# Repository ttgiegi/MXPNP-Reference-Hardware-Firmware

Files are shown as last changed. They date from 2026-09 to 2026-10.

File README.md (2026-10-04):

# MXPNP Legacy Hardware & Firmware

<p>
  <picture>
    <source media="(prefers-color-scheme: dark)" srcset="branding/c02/mxpnp-white.svg">
    MXPNP — by MX TECH / 萌新科技
  </picture>
</p>

[Official C02 SVG assets](branding/c02/)

This repository is a public reference archive for historical and superseded MXPNP hardware designs and legacy firmware.

## About

The contents represent earlier generations of MXPNP development. They may have been replaced by newer hardware and software architectures and are not expected to receive ongoing maintenance.

## Repository Scope

Released hardware designs may include manufacturing and reference material such as Gerber files, drill files, bills of materials (BOMs), pick-and-place files, schematic PDFs, and related documentation. Original CAD source files may not always be provided.

Legacy firmware may include modified versions or configurations of upstream projects, such as Marlin. Each component should retain its appropriate upstream attribution and license information.

## Repository Structure

```text
hardware/     Legacy hardware designs and manufacturing/reference files
firmware/     Legacy firmware sources and configurations
docs/         Design-specific notes and reference documentation
```

Directories will be added as legacy designs are archived.

## Status Labels

- `LEGACY`: Historical design retained for reference.
- `SUPERSEDED`: Replaced by a newer design or implementation.
- `EXPERIMENTAL`: Incomplete or intended for experimentation.
- `UNTESTED`: Not recently verified.

## Legacy Hardware

Hardware releases are provided for study, manufacturing of an older design, porting work, and experimentation. Availability and completeness vary by design.

### PCB Design Notes

Design-specific scope, upstream references, release contents, and known limitations are documented on these Wiki pages:

- [Smoothieware Control Board](https://github.com/ttgiegi/MXPNP-Reference-Hardware-Firmware/wiki/Smoothieware-Control-Board)
- [Six-Axis Pick-and-Place Mainboard](https://github.com/ttgiegi/MXPNP-Reference-Hardware-Firmware/wiki/Six%E2%80%90Axis-Pick%E2%80%90and%E2%80%90Place-Mainboard)
- [Nine-Axis Pick-and-Place Mainboard](https://github.com/ttgiegi/MXPNP-Reference-Hardware-Firmware/wiki/Nine%E2%80%90Axis-Pick%E2%80%90and%E2%80%90Place-Mainboard)
- [MXPNP Marlin v1.0 Motion Controller](https://github.com/ttgiegi/MXPNP-Reference-Hardware-Firmware/wiki/MXPNP-Marlin-v1.0-Motion-Controller)

## Legacy Mechanical Designs

The archive also includes historical CoreXY mechanical-design references for DIY study and experimentation. They are marked `LEGACY`, `EXPERIMENTAL`, and `UNTESTED`; they are not validated machine designs and are not recommended for direct production use.

The large design archives are distributed through the [CoreXY Mechanical Reference Release](https://github.com/ttgiegi/MXPNP-Reference-Hardware-Firmware/releases/tag/legacy-corexy-v1.0.0). See the [CoreXY Mechanical Reference Designs Wiki page](https://github.com/ttgiegi/MXPNP-Reference-Hardware-Firmware/wiki/CoreXY-Mechanical-Reference-Designs) for download guidance, checksums, and known limitations.

## Legacy Firmware

Firmware releases are retained as historical implementations and configurations. Compatibility with current MXPNP hardware or software is not guaranteed.

## Licensing and Attribution

License and attribution information, including applicable upstream notices, is provided with the relevant component where available.

## Current MXPNP Project

This repository is distinct from the current MXPNP project and its documentation. Refer to the current MXPNP project repository and documentation location when available: `CURRENT_MXPNP_PROJECT_URL`.

## Disclaimer

Legacy designs are provided for reference and experimentation. They are not guaranteed to be compatible with current MXPNP hardware or software, production-ready, safe, or actively supported unless a particular design explicitly states otherwise.

## Contact
For questions about uncertain or archive-specific information, contact `1025971921@qq.com`.

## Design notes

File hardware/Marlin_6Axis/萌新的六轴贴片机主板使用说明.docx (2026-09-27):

# 萌新的六轴贴片机主板使用说明

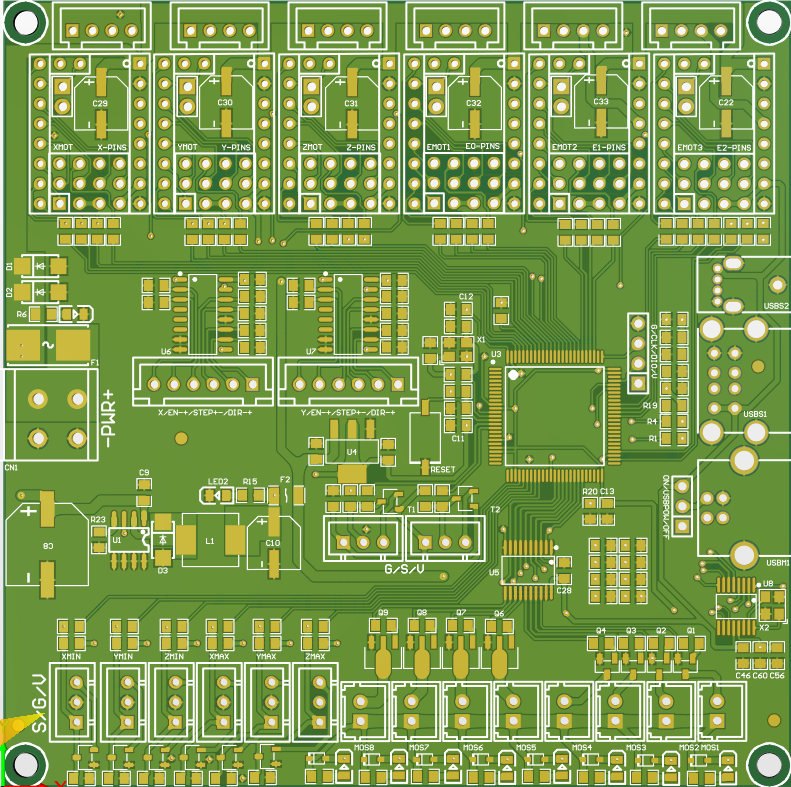
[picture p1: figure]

## 一：萌新主板简介

萌新六轴主板是本萌新针对openpnp项目开发的专用于双贴头的高性价比运动控制板，特别适用于DIY的小型贴片机使用。

## 二：萌新主板特点

1）采用32位主频72MHz的ARM级Cortex-M3系列stm32103ve主控芯片，性能大幅提升；

2）搭载高度模块化开源固件Marlin2.0，方便用户DIY及二次开发；

3）板载TMC驱动的SPI工作模式和UART工作模式，且板载DIAG功能引脚，方便客户使用，省去复杂的接线过程，只需通过简单的拔插跳线帽即可使用；

4）采用高性能MOSFET管，驱动8路外设满足小型机使用需求；

5）采用可拔插的保险丝，更换过程更加简易；

6）使用电源选择设计，让USB电源与开关电源分开，有效避免由于短路导致电脑USB口被烧毁的情况发生；

7）预留闭环驱动接口，省去外插转接模块的烦恼；

8）双Y轴接口，省去外接驱动拓展模块的烦恼；

9）压力传感器接口使用钳位二极管进行保护，增强接口的抵抗能力；

## 三：萌新主板参数

外观尺寸：100*100mm

安装尺寸：94.5*94.5mm

微处理器：ARM Cortex-M3 CPU

输入电压：DC24V

逻辑电压：DC 3.3V

电机驱动器：支持TMC5161、TMC5160、TMC2209、TMC2225、TMC2208、TMC2130、ST820、LV8729、DRV8825、A4988等，可单独外接电机驱动

驱动工作模式支持：SPI、UART、STEP/DIR

电机驱动接口：X、Y、Y2、Z、A、 B，六路（X和Y有一个闭环驱动接口），最高可达256细分

真空传感器接口：T0、T1。2路

PC通信接口：方形USB，方便插拔，通信波特率115200

支持文件格式：G-code

支持机器结构：XYZ、delta、kossel、Ultimaker、corexy

## 四：萌新主板通电

此处为24v供电输入，注意不可接反！！

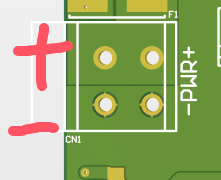
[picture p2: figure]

此处跳线帽用于选择是用USB给主板供电还是24V给主板供电 跳线帽连接靠上两个引脚为usb供电靠下为24v，正常使用建议连接靠下两个

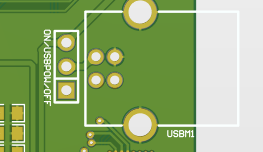
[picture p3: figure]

## 五、主板与电脑通信

主板通过【USB】接口与电脑通信，需要电脑先安装驱动程序后，再将主板插入电脑，方可识别端口进行数据传输。WINDOWS一般会自动安装，如果不识别考虑安装驱动程序。

## 六、主板接口说明

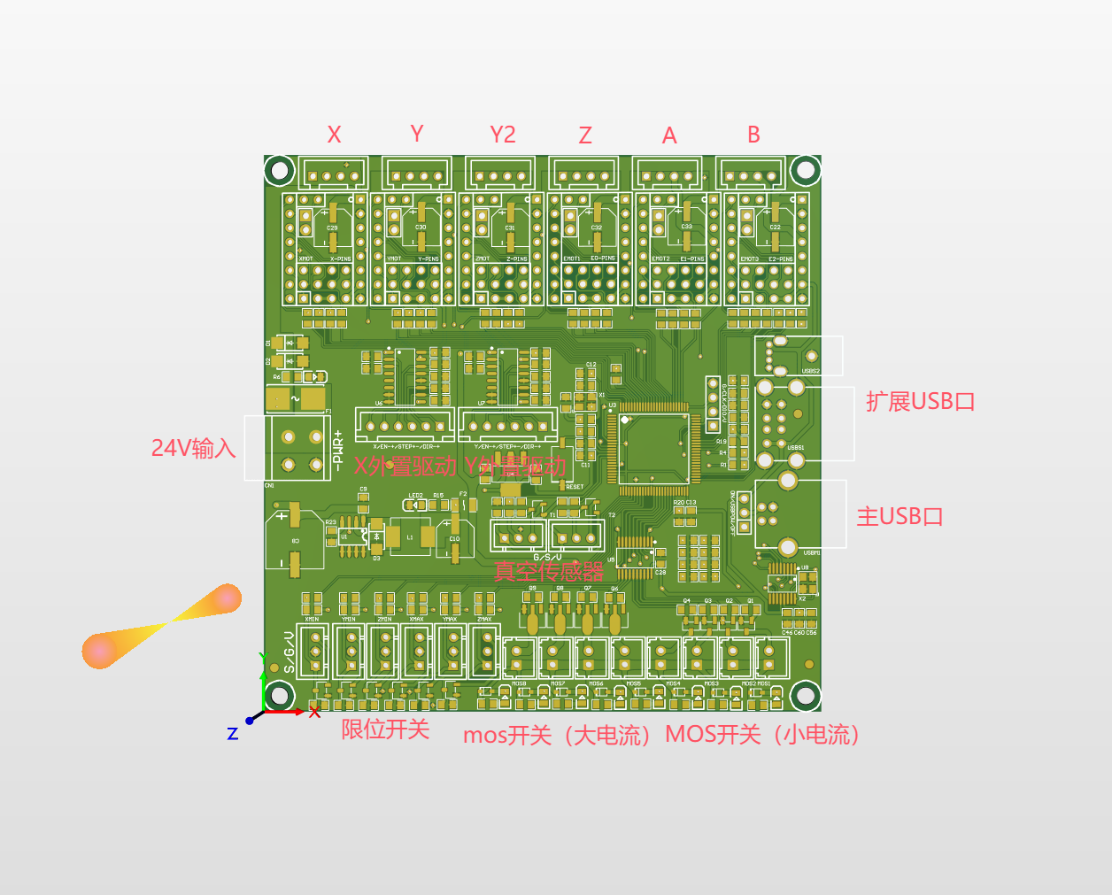
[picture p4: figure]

电机接口如上图标注，默认引脚定义如上图如果需要重新修改可在固件中进行重映射。电机接口四个引脚从左往右相邻两个引脚为电机的一相。两相顺序更换之后只会影响电机旋转方向。24V输入接口上正下负不可接反！！！板子中间两个6p接口分别为外接XY轴驱动的差分信号输出口，具体线序参照板子上的丝印。限位开关接口板子上标出了定义，MIN为最小限位，MAX为最大限位。左侧标注的s/g/v分别表示横向那一排引脚的定义，s代表限位信号g为地，V为5v供电。Mos开关左侧四个接口为大封装mos可以带一些电流比较大的负载例如气泵，右侧4个为小封装可以带一些小电流负载例如补光灯，小电磁阀等。正负极引脚定义如图

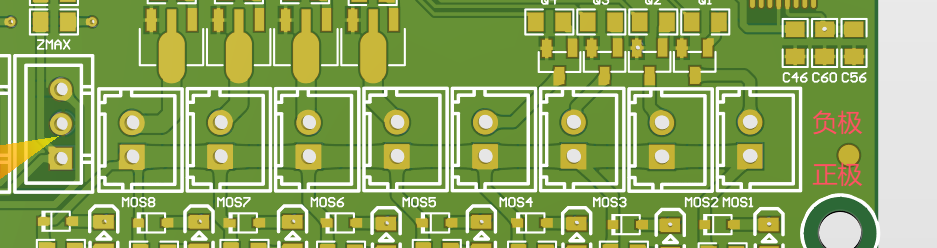
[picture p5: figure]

以上MOS开关由自定义G代码控制格式以及使用方法如图

主USB口连接电脑，其余扩展口可用于连接摄像头以及飞达控制器等。

驱动工作模式选择方法：

1 普通的STEP/DIR模式：（如：A4988、DRV8825、LV8729、ST820等）根据驱动细分表来选择短路帽短接MS1-MS2。

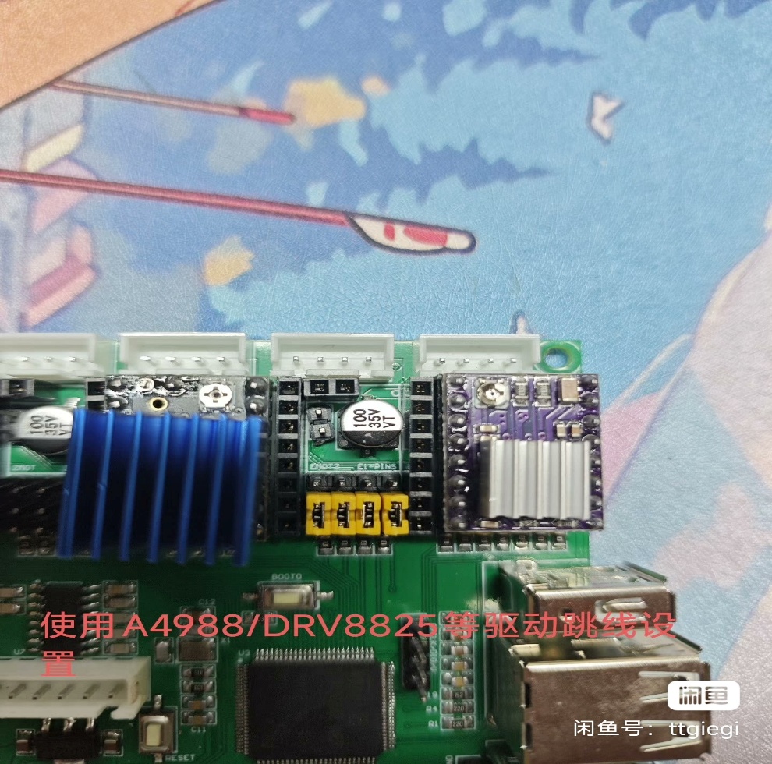
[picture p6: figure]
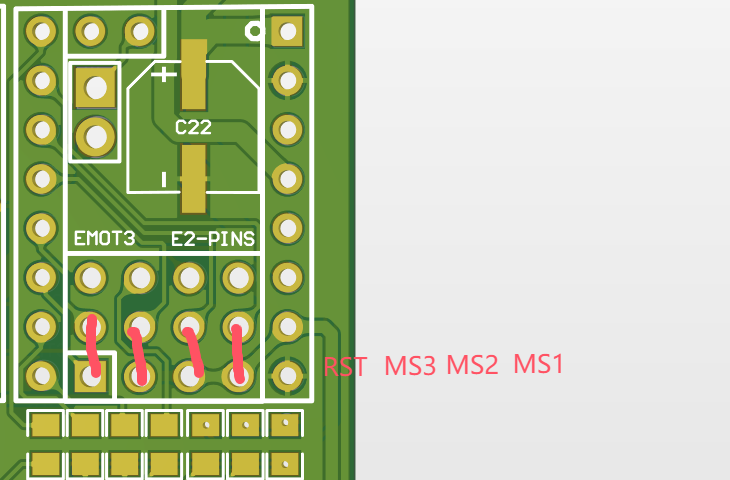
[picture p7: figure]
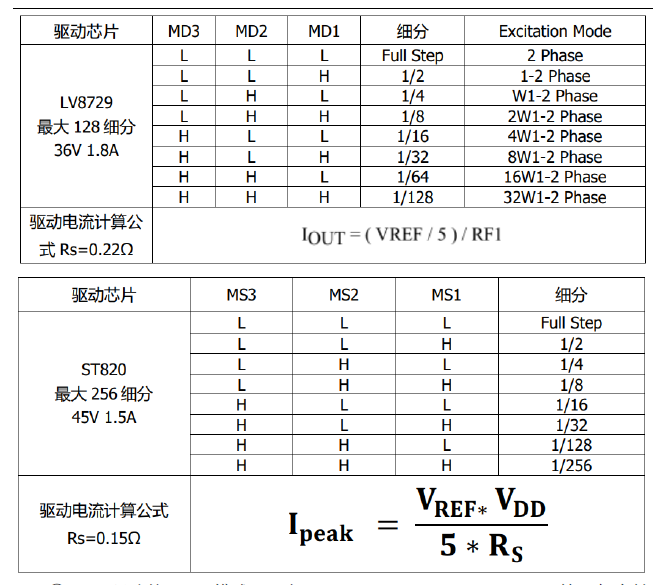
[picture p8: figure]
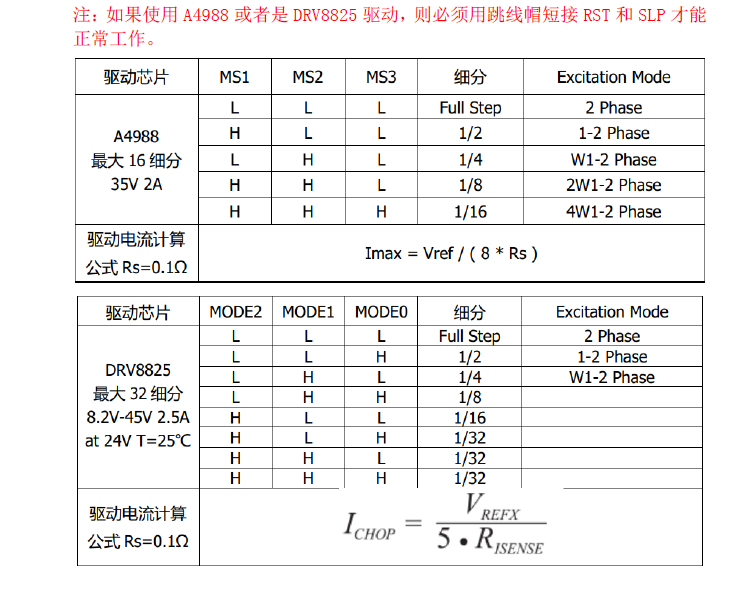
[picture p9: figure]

② TMC驱动的UART模式：（如：TMC2208、TMC2209、TMC2225等）每个轴使用一个短路帽短接图中红框位置即可，细分和驱动电流通过固件进行设置。

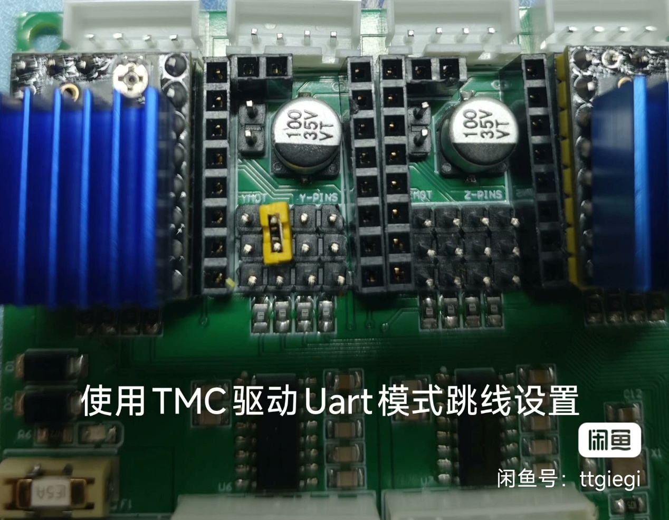
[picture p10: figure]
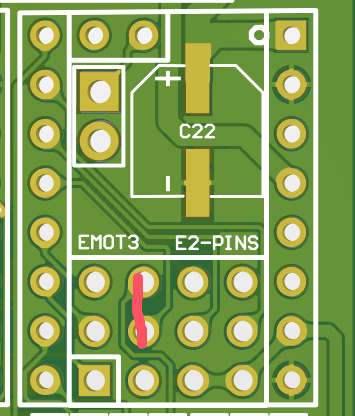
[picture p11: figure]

③ TMC驱动的SPI模式：（如：TMC2130、TMC5160、TMC5161等）每个轴使用四个短路帽短接图中红框位置即可，细分和驱动电流通过固件进行设置。

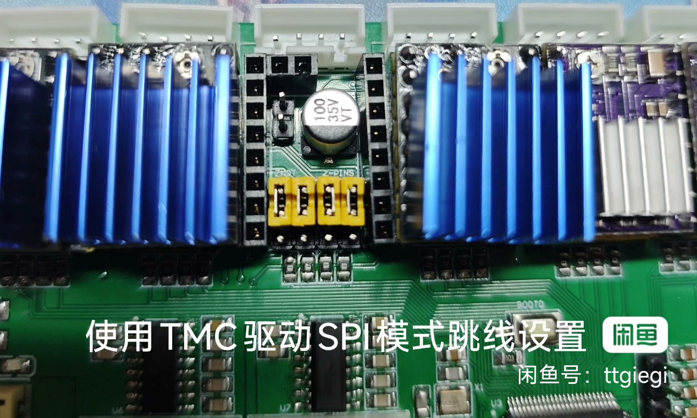
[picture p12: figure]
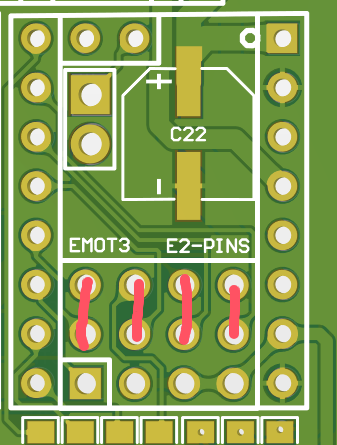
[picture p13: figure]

如果需要使用无限位归零那么需要连接跳线帽如图所示

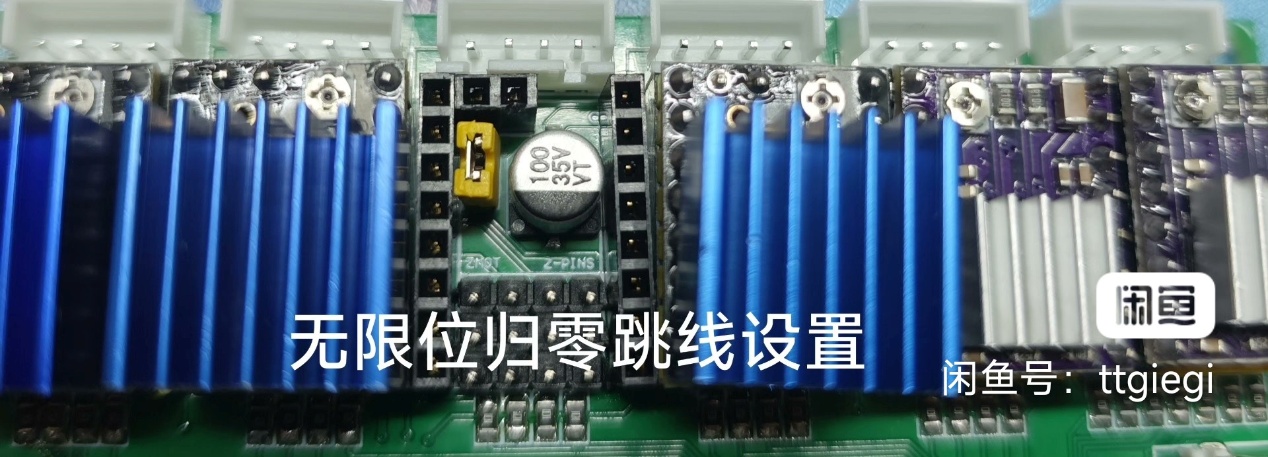
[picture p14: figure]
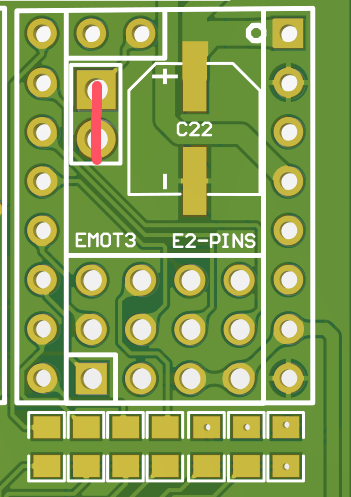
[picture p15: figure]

6个驱动的无限位归零信号分别连接到X-XMIN/Y-YMIN/Y2-ZMIN/Z-XMAX/A-YMAX/B-ZMAX

以上定义均可自己在固件中修改。

## 七、固件编译与修改

主板采用Marlin2作为固件，具有很高的使用自由度，几乎兼容各种结构的机器。

编译环境搭建可以参照以下链接

https://blog.csdn.net/jslovesky/article/details/110133431

第一步安装vscode 不再赘述

第二步进入vscode后点击

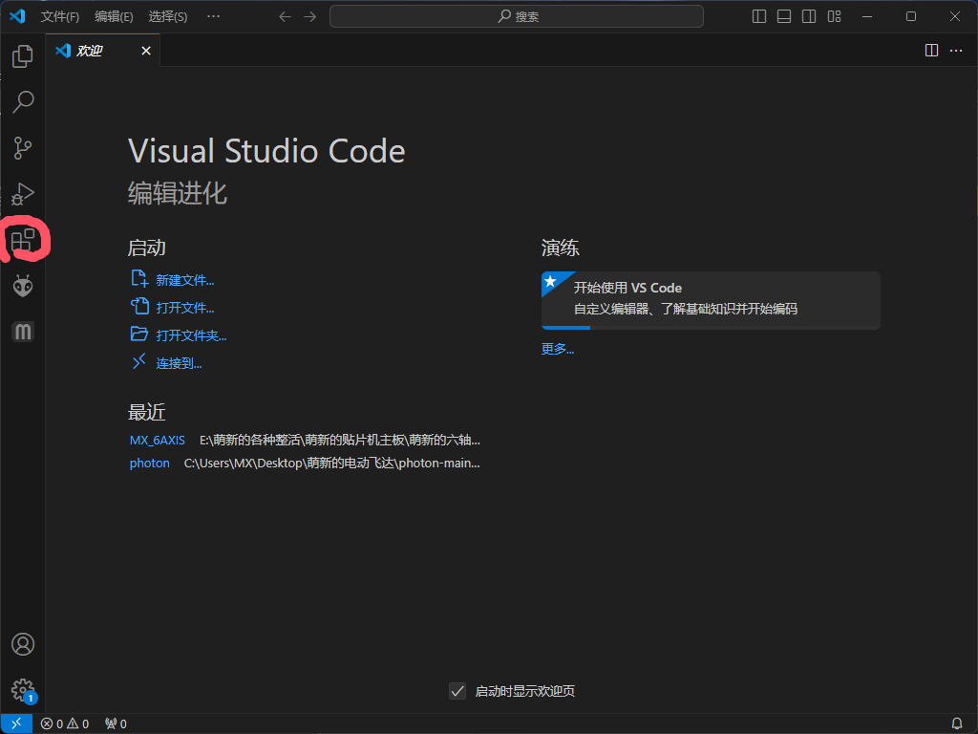
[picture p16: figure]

在其中搜索platformio并且安装整个过程基本上自动完成

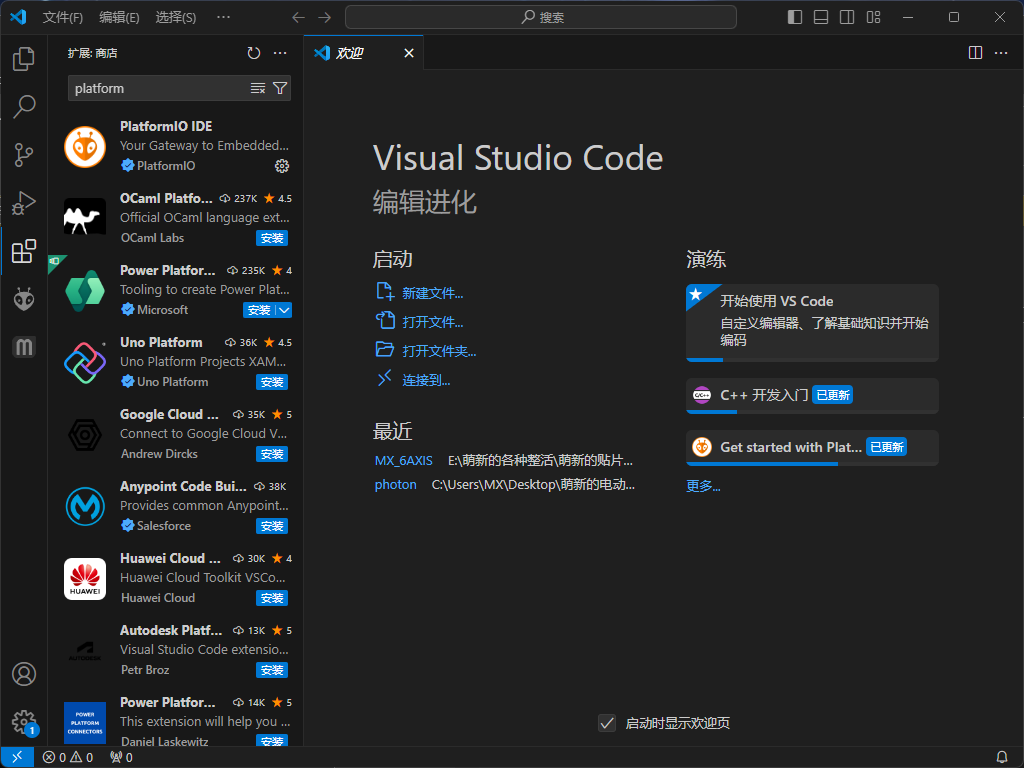
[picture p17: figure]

安装完成后点击vscode的 文件-打开文件夹 选中萌新提供的固件包，编译的相关参数已经配置好，只需要根据自己的需要修改configuration,h以及configuration.adv.h中的相关内容并且编译即可使用下载器上传进主板中使用

编译出的固件的路径如下.pio\build\STM32F103VE

名字叫firmware.bin

如何修改固件有很多教程这里不再赘述。

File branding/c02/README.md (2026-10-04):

# MX TECH / MXPNP — C02 brand assets

Approved identity: C02 (开放方切), adopted on 2026-10-04. MXPNP is a project of MX TECH / 萌新科技; both share the same geometric symbol.

<picture>
  <source media="(prefers-color-scheme: dark)" srcset="mxpnp-white.svg">
  MXPNP — by MX TECH / 萌新科技
</picture>

## SVG files

| Asset | Primary | Black / PCB | White / dark backgrounds |
| --- | --- | --- | --- |
| Shared icon | [icon.svg](icon.svg) | [icon-mono.svg](icon-mono.svg) | [icon-white.svg](icon-white.svg) |
| MX TECH + 萌新科技 | [mx-tech.svg](mx-tech.svg) | [mx-tech-mono.svg](mx-tech-mono.svg) | [mx-tech-white.svg](mx-tech-white.svg) |
| MXPNP + studio credit | [mxpnp.svg](mxpnp.svg) | [mxpnp-mono.svg](mxpnp-mono.svg) | [mxpnp-white.svg](mxpnp-white.svg) |
| Studio wordmark | [wordmark.svg](wordmark.svg) | [wordmark-mono.svg](wordmark-mono.svg) | [wordmark-white.svg](wordmark-white.svg) |

All SVGs have transparent backgrounds and outlined lettering. They contain native vector paths without embedded bitmaps, external fonts, gradients or filters. Primary color: `#173B4B`; monochrome: `#000000`; reversed: `#FFFFFF`.

The README and Wiki use the primary version on light backgrounds and the reversed version on dark backgrounds. Use monochrome exports for PCB silkscreen or engraving, and check the letter openings at the intended manufacturing size.

These are approved exports of the C02 master maintained in the MXPNP application repository. They provide project identity; hardware status, compatibility and upstream attribution remain documented with each archived design.

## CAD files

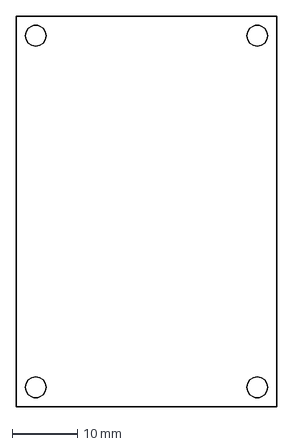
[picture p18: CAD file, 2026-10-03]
hardware/MXPNP_Marlin_v1.0/MXPNP_V1.0_ToolHead/mxpnp一代集线板.DXF
40.0 x 60.0 mm

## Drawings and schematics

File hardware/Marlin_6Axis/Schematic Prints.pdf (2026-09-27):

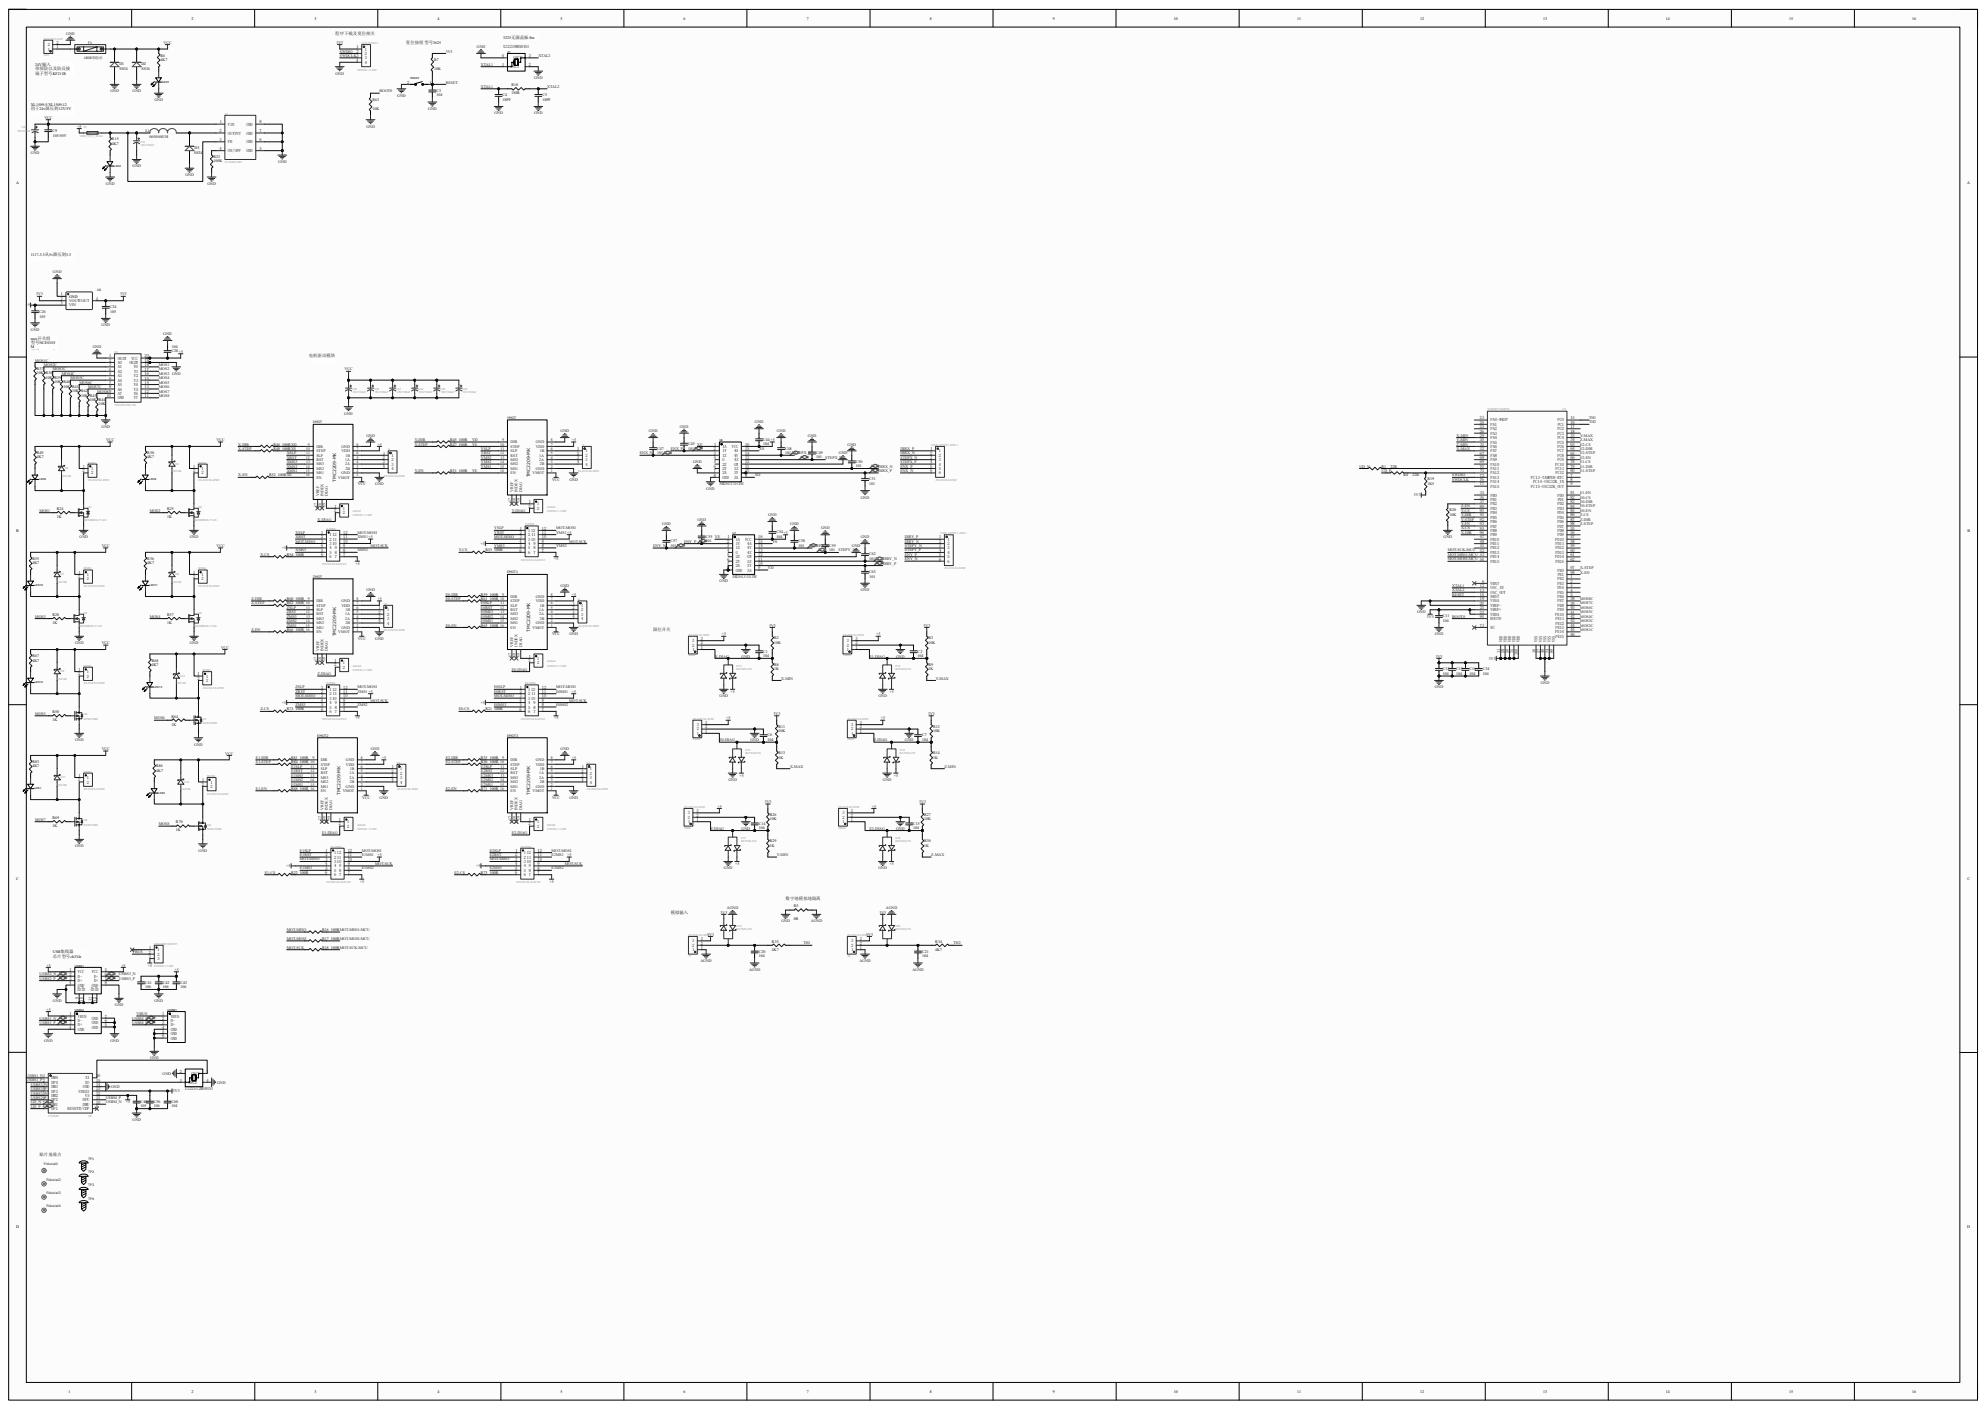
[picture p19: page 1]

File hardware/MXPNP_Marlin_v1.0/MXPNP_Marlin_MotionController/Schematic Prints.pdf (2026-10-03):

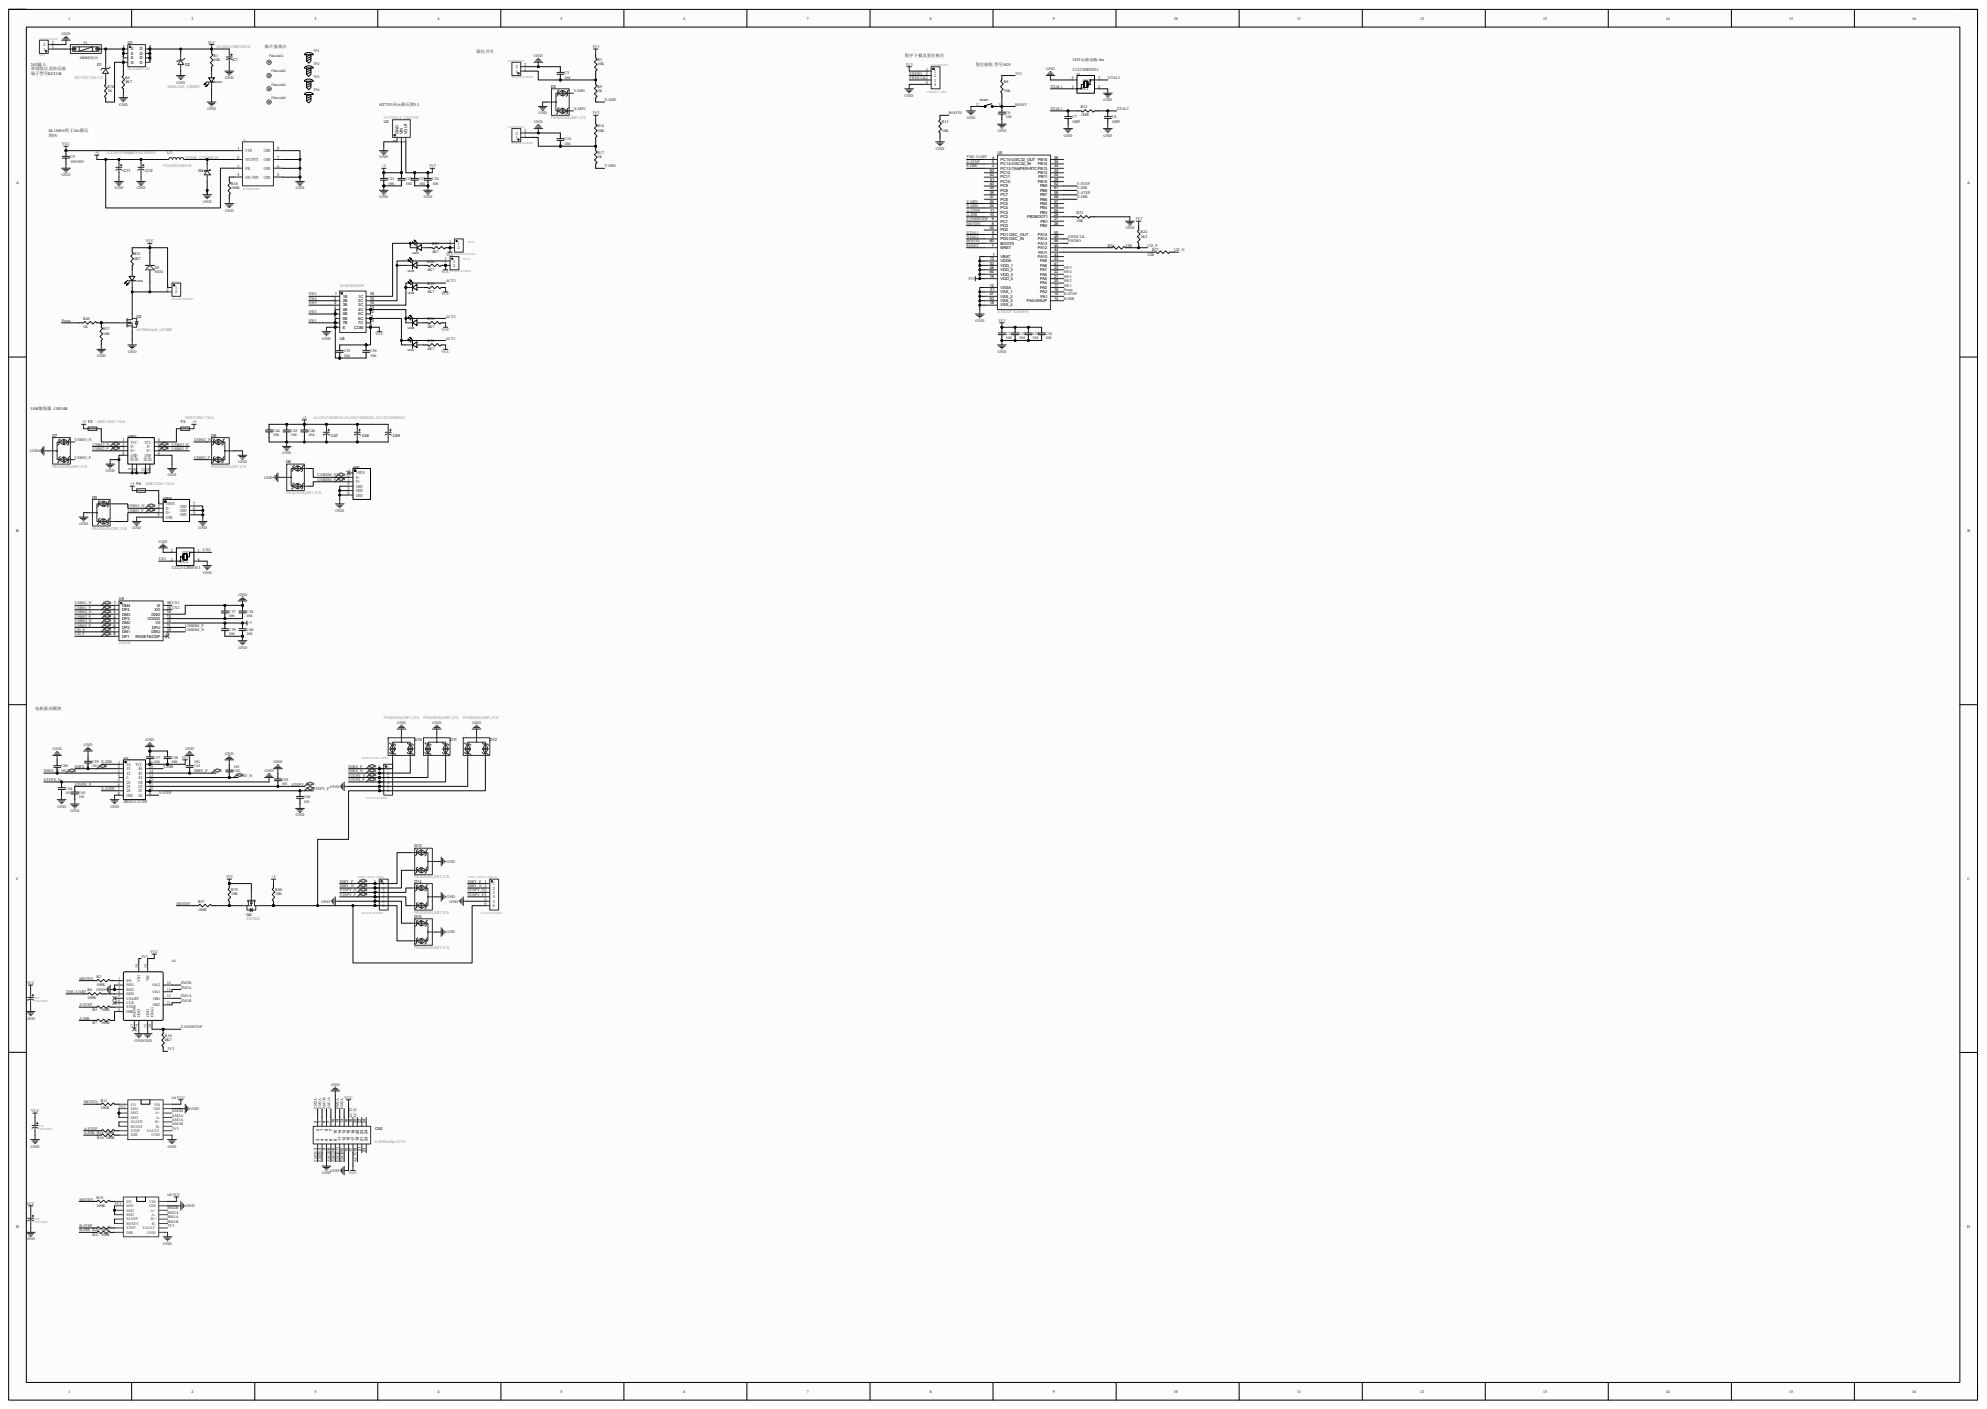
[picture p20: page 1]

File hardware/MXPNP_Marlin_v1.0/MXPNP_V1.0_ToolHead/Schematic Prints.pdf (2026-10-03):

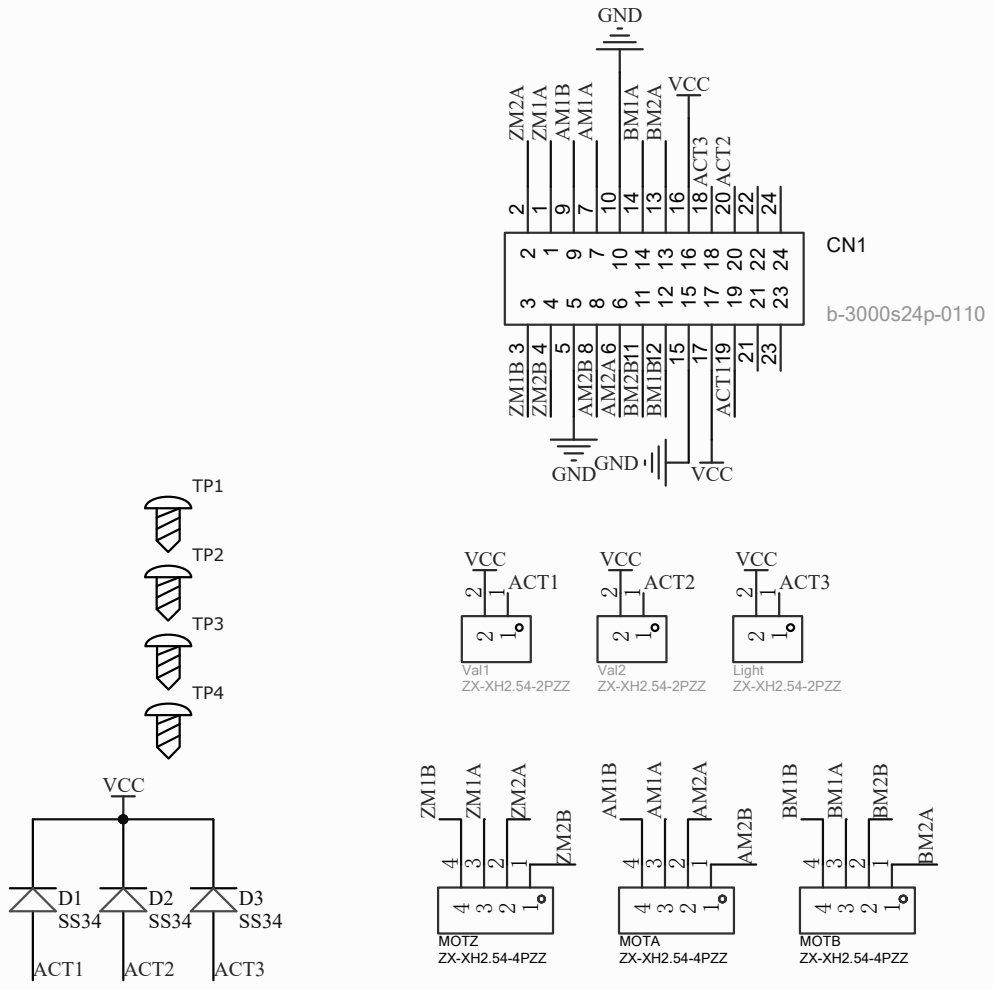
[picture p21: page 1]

Size A2 | Number | Revision

Date: 10/03/2026 | Sheet of
File: C:\Users\..\MXPNP一代集线板.SchDoc Drawn By:

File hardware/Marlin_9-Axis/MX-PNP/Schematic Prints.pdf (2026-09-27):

6 6 | 5 5 | 4 4 | 3 3 | 2 2 | 1 1

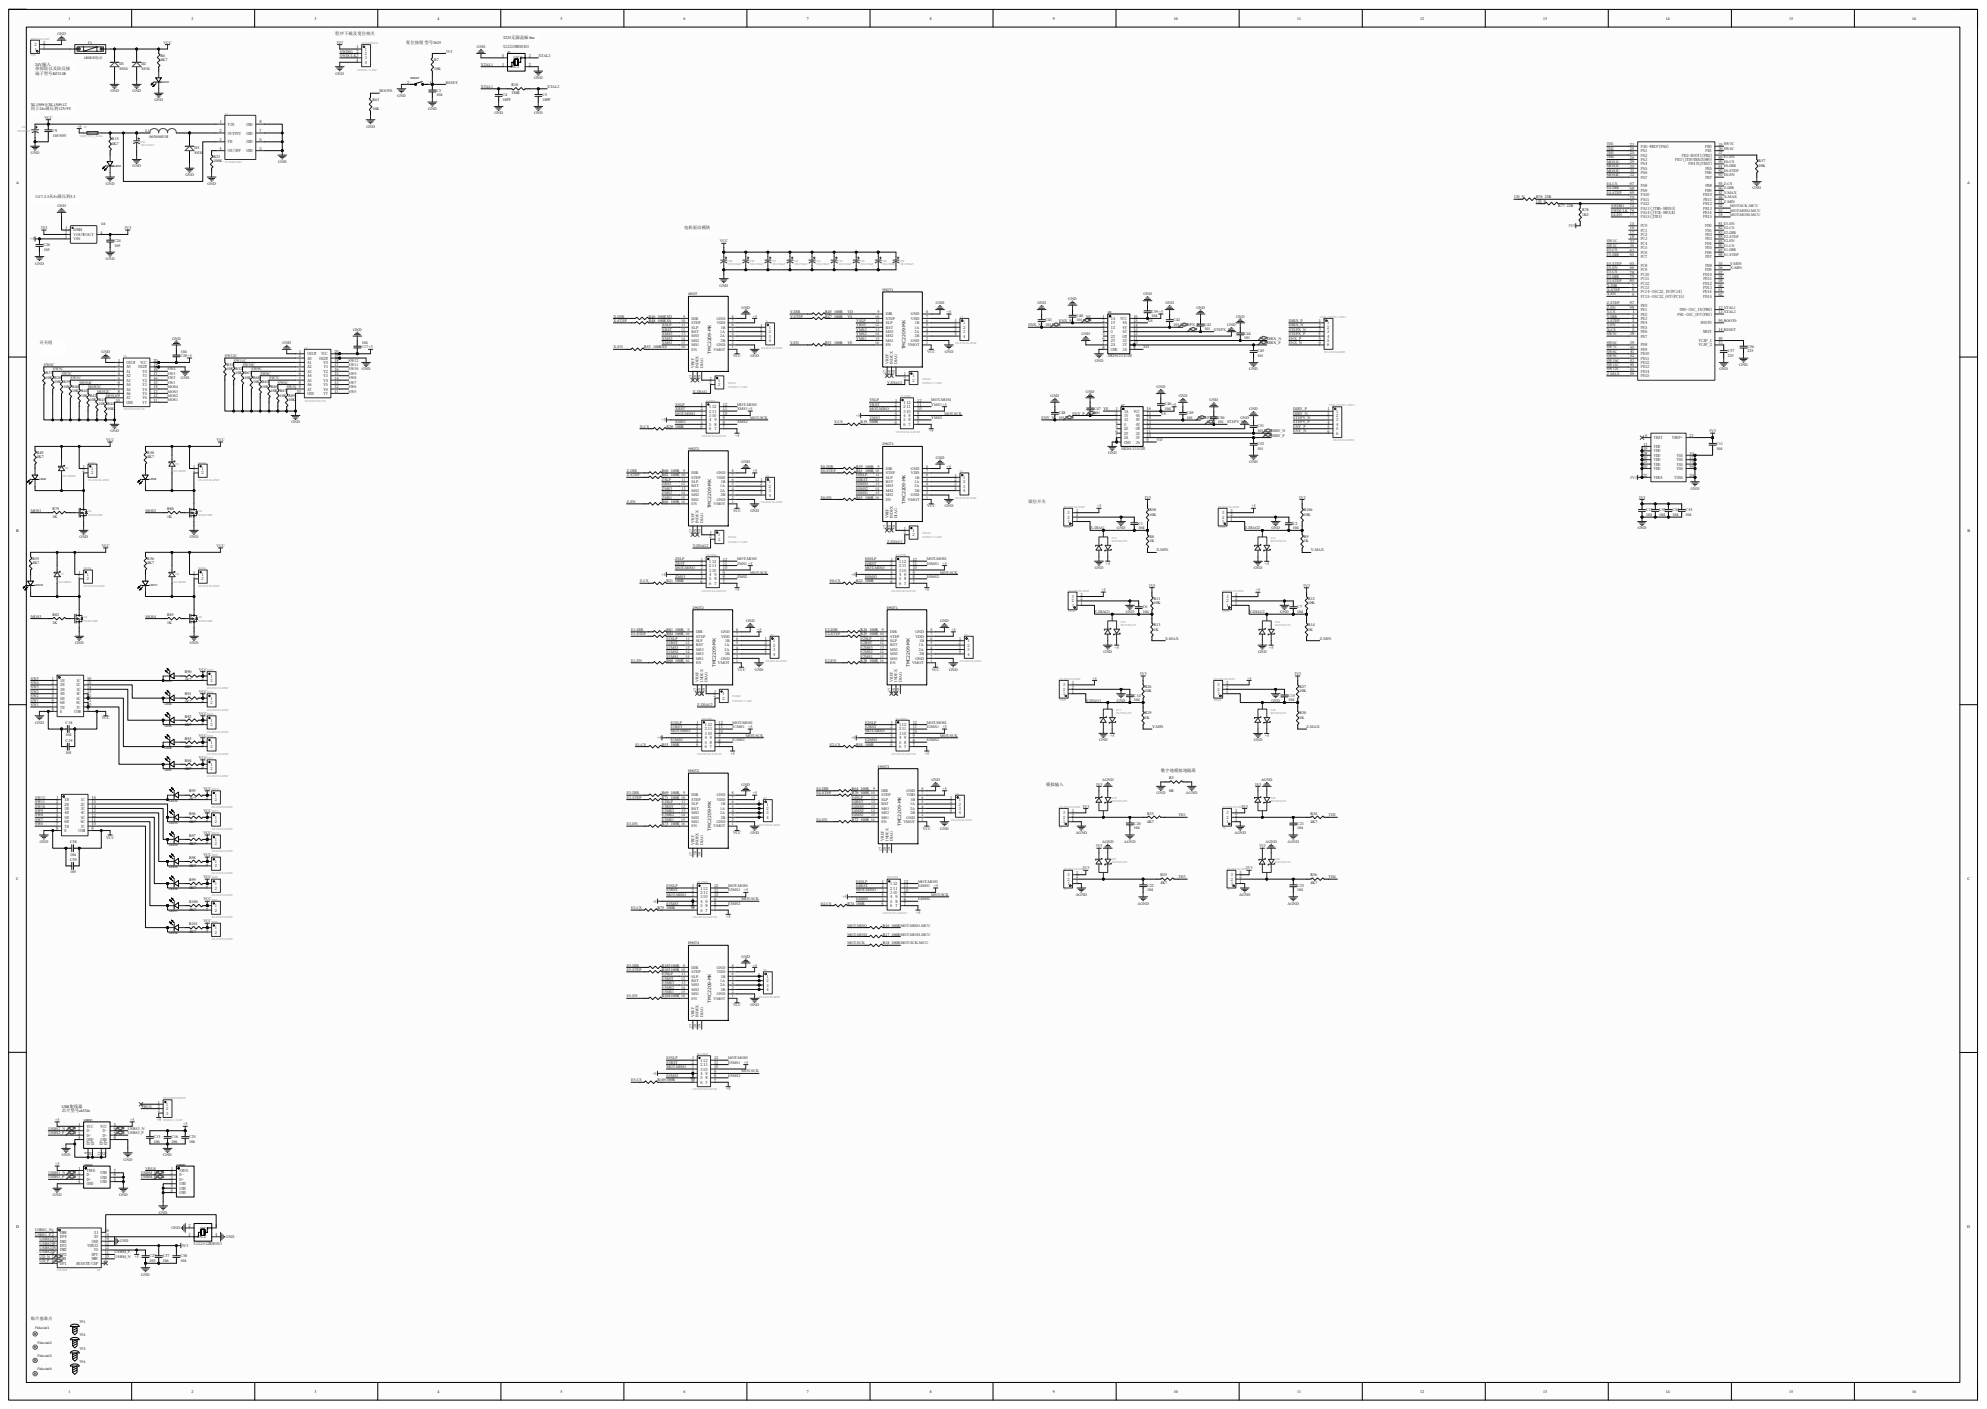
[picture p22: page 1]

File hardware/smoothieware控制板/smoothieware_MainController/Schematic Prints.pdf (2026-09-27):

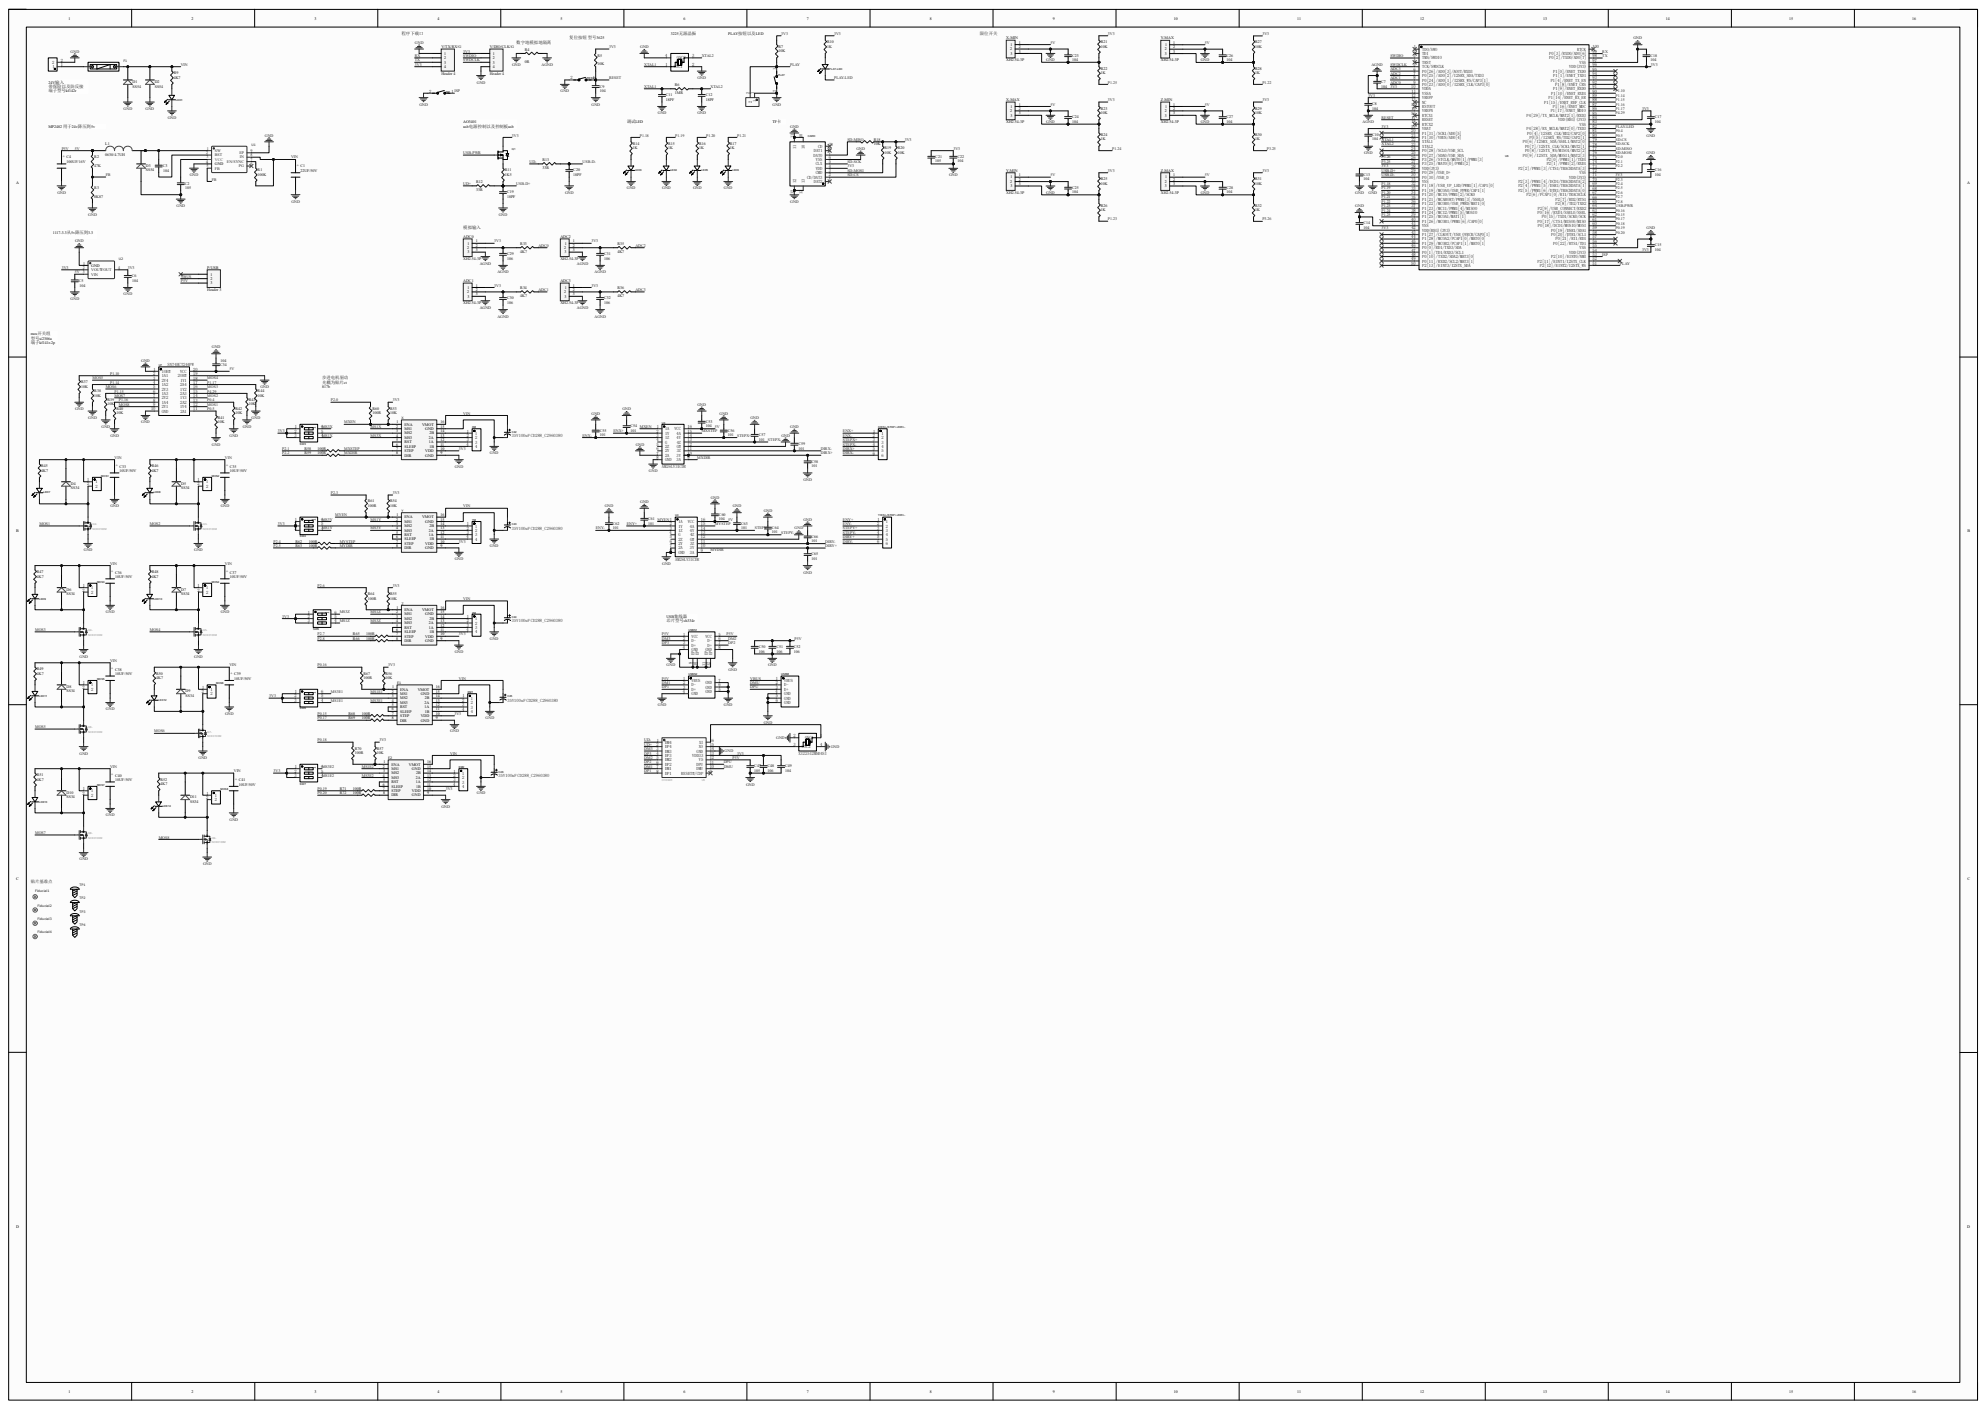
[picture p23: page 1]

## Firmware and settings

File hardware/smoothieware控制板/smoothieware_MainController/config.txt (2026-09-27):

# Smoothieboard configuration file, see http://smoothieware.org/configuring-smoothie
# NOTE Lines must not exceed 132 characters, and '#' characters mean what follows is ignored
## Robot module configurations : general handling of movement G-codes and slicing into moves

# Basic motion configuration
default_feed_rate                            4000             # Default speed (mm/minute) for G1/G2/G3 moves
default_seek_rate                            4000             # Default speed (mm/minute) for G0 moves
mm_per_arc_segment                           0.0              # Fixed length for line segments that divide arcs, 0 to disable
#mm_per_line_segment                         5                # Cut lines into segments this size
mm_max_arc_error                             0.01             # The maximum error for line segments that divide arcs 0 to disable
                                                              # note it is invalid for both the above be 0
                                                              # if both are used, will use largest segment length based on radius

# Arm solution configuration : Cartesian robot. Translates mm positions into stepper positions
# See http://smoothieware.org/stepper-motors
alpha_steps_per_mm                           100               # Steps per mm for alpha ( X ) stepper
beta_steps_per_mm                            100               # Steps per mm for beta ( Y ) stepper
gamma_steps_per_mm                           200             # Steps per mm for gamma ( Z ) stepper

# Planner module configuration : Look-ahead and acceleration configuration
# See http://smoothieware.org/motion-control
acceleration                                 3000             # Acceleration in mm/second/second.
#z_acceleration                              500              # Acceleration for Z only moves in mm/s^2, 0 uses acceleration which is the default. DO NOT SET ON A DELTA
junction_deviation                           0.05             # See http://smoothieware.org/motion-control#junction-deviation
#z_junction_deviation                        0.0              # For Z only moves, -1 uses junction_deviation, zero disables junction_deviation on z moves DO NOT SET ON A DELTA

# Cartesian axis speed limits
x_axis_max_speed                             120000            # Maximum speed in mm/min
y_axis_max_speed                             100000            # Maximum speed in mm/min
z_axis_max_speed                             30000             # Maximum speed in mm/min

# Stepper module configuration
# Pins are defined as  ports, and pin numbers, appending "!" to the number will invert a pin
# See http://smoothieware.org/pin-configuration and http://smoothieware.org/pinout
alpha_step_pin                             2.1              # Pin for alpha stepper step signal
alpha_dir_pin                                2.2!              # Pin for alpha stepper direction, add '!' to reverse direction
alpha_en_pin                                2.0              # Pin for alpha enable pin
alpha_max_rate                               120000.0          # Maximum rate in mm/min

beta_step_pin                               2.4              # Pin for beta stepper step signal
beta_dir_pin                                 2.5            # Pin for beta stepper direction, add '!' to reverse direction
beta_en_pin                                2.3             # Pin for beta enable
beta_max_rate                                100000.0          # Maxmimum rate in mm/min

gamma_step_pin                               2.7              # Pin for gamma stepper step signal
gamma_dir_pin                               2.8!             # Pin for gamma stepper direction, add '!' to reverse direction
gamma_en_pin                                 2.6             # Pin for gamma enable
gamma_max_rate                              30000.0            # Maximum rate in mm/min


# A axis

 delta_steps_per_mm                           17.7778             # may be steps per degree for example
 delta_step_pin                               0.15              # Pin for delta stepper step signal
 delta_dir_pin                               0.17!             # Pin for delta stepper direction
 delta_en_pin                                0.16              # Pin for delta enable
delta_max_rate                               60000            # mm/min
delta_acceleration                           6000.0            # mm/secÂ²

# B axis

epsilon_steps_per_mm                          17.7778              # may be steps per degree for example
epsilon_step_pin                              0.19              # Pin for delta stepper step signal
epsilon_dir_pin                               0.20!            # Pin for delta stepper direction
epsilon_en_pin                                0.18             # Pin for delta enable
epsilon_max_rate                              60000            # mm/min
epsilon_acceleration                          6000.0            # mm/secÂ²


# First hotend configuration
temperature_control.hotend.enable            true             # Whether to activate this ( "hotend" ) module at all.
temperature_control.hotend.thermistor_pin    0.23             # Pin for the thermistor to read
temperature_control.hotend.heater_pin        nc              # Pin that controls the heater, set to nc if a readonly thermistor is being defined
temperature_control.hotend.thermistor        EPCOS100K        # See http://smoothieware.org/temperaturecontrol#toc5
#temperature_control.hotend.beta             4066             # Or set the beta value
temperature_control.hotend.set_m_code        104              # M-code to set the temperature for this module
temperature_control.hotend.set_and_wait_m_code 109            # M-code to set-and-wait for this module
temperature_control.hotend.designator        T                # Designator letter for this module
#temperature_control.hotend.max_temp         300              # Set maximum temperature - Will prevent heating above 300 by default
#temperature_control.hotend.min_temp         0                # Set minimum temperature - Will prevent heating below if set

# Safety control is enabled by default and can be overidden here, the values show the defaults
# See http://smoothieware.org/temperaturecontrol#runaway
#temperature_control.hotend.runaway_heating_timeout      900  # How long it can take to heat up, max is 2040 seconds.
#temperature_control.hotend.runaway_cooling_timeout        0  # How long it can take to cool down if temp is set lower, max is 2040 seconds
#temperature_control.hotend.runaway_range                20   # How far from the set temperature it can wander, max setting is 63°C

# PID configuration
# See http://smoothieware.org/temperaturecontrol#pid
#temperature_control.hotend.p_factor         13.7             # P ( proportional ) factor
#temperature_control.hotend.i_factor         0.097            # I ( integral ) factor
#temperature_control.hotend.d_factor         24               # D ( derivative ) factor

#temperature_control.hotend.max_pwm          64               # Max pwm, 64 is a good value if driving a 12v resistor with 24v.

# Second hotend configuration
#temperature_control.hotend2.enable            true           # Whether to activate this ( "hotend" ) module at all.
#temperature_control.hotend2.thermistor_pin    0.25           # Pin for the thermistor to read
#temperature_control.hotend2.heater_pin        nc           # Pin that controls the heater
#temperature_control.hotend2.thermistor        EPCOS100K      # See http://smoothieware.org/temperaturecontrol#thermistor
##temperature_control.hotend2.beta             4066           # or set the beta value
#temperature_control.hotend2.set_m_code        104            # M-code to set the temperature for this module
#temperature_control.hotend2.set_and_wait_m_code 109          # M-code to set-and-wait for this module
#temperature_control.hotend2.designator        T1             # Designator letter for this module

#temperature_control.hotend2.p_factor          13.7           # P ( proportional ) factor
#temperature_control.hotend2.i_factor          0.097          # I ( integral ) factor
#temperature_control.hotend2.d_factor          24             # D ( derivative ) factor

#temperature_control.hotend2.max_pwm          64              # Max pwm, 64 is a good value if driving a 12v resistor with 24v.
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

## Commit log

2026-09-27 添加开源资料
    [config.txt]
2026-09-27 Link PCB design notes from README
2026-10-03 Add MXPNP Marlin v1.0 controller reference
    [mx-pnp_Copper_Signal_Bot.gbr, mx-pnp_Copper_Signal_Top.gbr, mx-pnp_Drawing_1.gbr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]
2026-10-03 推送新资料
    [mx-pnp_Copper_Signal_Bot.gbr, mx-pnp_Copper_Signal_Top.gbr, mx-pnp_Drawing_1.gbr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]
